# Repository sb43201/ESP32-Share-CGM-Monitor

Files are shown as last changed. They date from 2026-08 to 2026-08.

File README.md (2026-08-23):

# ESP32 Share CGM Desktop Monitor

An unofficial ESP32 desktop monitor that can display glucose data from a
Dexcom G7 CGM system through Dexcom Share.

Firmware **V3.1.0** targets the Hosyond/LCDWiki E32R35T desktop display:
ESP32-WROOM-32E, 480x320 ST7796 TFT, XPT2046 resistive touch, and onboard
microSD.

This is an independent community project. It is not affiliated with, authorized
by, sponsored by, or endorsed by Dexcom, Inc. The monitor retrieves readings
through an unofficial/private Dexcom Share interface over Wi-Fi and does not
communicate directly with a sensor over Bluetooth. That interface may change or
stop working without notice.

This project is an independent, noncommercial, open-source experimental passive
secondary CGM display. It has not been reviewed, cleared, or approved by FDA and
must not be relied upon for treatment decisions, medical alarms, diagnosis, or
replacement of an approved CGM application or receiver. Confirm unexpected
readings and alerts using the approved CGM workflow.

## V3.1.0 features

- live glucose value with Dexcom-provided trend arrow and description;
- color-coded glucose: red below 70, green from 70–180, and yellow above 180 mg/dL;
- touch-selectable 3H, 6H, 12H, and 24H TFT graphs with the last range
  restored after reboot;
- 70, 180, and 250 mg/dL graph references with a flashing visual threshold
  warning below 65 or above 250 mg/dL;
- persistent daily CSV logging to the onboard microSD slot;
- recovery of recent graph history after reboot;
- responsive web dashboard with live glucose, statistics, and 3H–30D history;
- streamed, downsampled 7D and 30D requests with bounded ESP32 memory use;
- CSV export for today, seven days, or a validated date range;
- captive-portal Wi-Fi and Dexcom publisher-account provisioning;
- configurable POSIX timezone, 12/24-hour clock, and screen-off schedule;
- center double-tap screen-off and touch-to-wake with temporary schedule override;
- TFT and web controls for clock format and four-point touch recalibration;
- graceful Wi-Fi, Dexcom, and SD failure recovery.

## Hardware mapping

| Function | ESP32 pin / bus |
|---|---:|
| TFT CS | GPIO 15, HSPI |
| TFT DC | GPIO 2 |
| TFT SCLK | GPIO 14 |
| TFT MOSI | GPIO 13 |
| TFT MISO | GPIO 12 |
| TFT backlight | GPIO 27 |
| Touch CS | GPIO 33, HSPI |
| Touch IRQ | GPIO 36 |
| SD CS | GPIO 5, VSPI |
| SD SCK | GPIO 18 |
| SD MISO | GPIO 19 |
| SD MOSI | GPIO 23 |

## Project media and enclosure

- [Project images](docs/images/) contains photographs, screenshots, and
  documentation graphics.
- [3D-printed enclosure](hardware/enclosure/) contains CAD, printable files,
  fabrication guidance, and assembly notes.

## Build and upload

Requirements: VS Code with PlatformIO, or PlatformIO Core.

```powershell
cd "PATH\TO\ESP32-Share-CGM-Monitor"
& "$env:USERPROFILE\.platformio\penv\Scripts\platformio.exe" run
& "$env:USERPROFILE\.platformio\penv\Scripts\platformio.exe" run -t upload --upload-port COM12
& "$env:USERPROFILE\.platformio\penv\Scripts\platformio.exe" device monitor --port COM12 --baud 115200
```

Change `COM12` if PlatformIO reports a different port. Close every serial monitor
before erase or upload operations.

To reproduce the complete first-boot workflow:

```powershell
& "$env:USERPROFILE\.platformio\penv\Scripts\platformio.exe" run -t erase --upload-port COM12
& "$env:USERPROFILE\.platformio\penv\Scripts\platformio.exe" run -t upload --upload-port COM12
```

## First boot

1. Complete the four-point touch calibration.
2. Read the welcome and safety screens; each remains visible for two seconds.
3. Join the displayed `CGMMonitor-Setup-XXXXXX` access point.
4. Open `http://192.168.4.1` if the captive page does not appear.
5. Select a 2.4 GHz Wi-Fi network.
6. Enter the Dexcom **publisher/sharer** login and password, not follower credentials.
7. Configure the hostname, timezone, clock, and optional screen schedule.
8. Save and wait for NTP, SD restoration, and Dexcom authentication.

Dexcom Share must be enabled with at least one follower configured. The saved
password is never returned by the dashboard or printed to Serial.

After the monitor joins the local network, open the dashboard at
`http://HOSTNAME.local` (normally `http://esp32-cgm-monitor.local`) or use the
IP address shown on the TFT System Status page. The `.local` address uses mDNS;
client devices or segmented networks without multicast DNS support must use the
numeric IP address.

## SD storage

The independent VSPI microSD interface writes one FAT32-compatible CSV file per
local day:

```text
/dexcom/YYYY/MM/YYYY-MM-DD.csv
```

Stable schema:

```csv
timestamp_iso,epoch_ms,glucose_mgdl,trend,trend_text
```

Epoch milliseconds are the canonical deduplication key. Each new record is
opened, appended, flushed, and closed. The logger warns below 100 MB free and
stops below 20 MB without interrupting glucose monitoring. Existing files are
never automatically deleted in V3.1.0.

## Web API

| Endpoint | Purpose |
|---|---|
| `/` | Responsive dashboard and settings |
| `/status` | Time, current glucose, SD, and non-secret device status |
| `/api/history?range=3h` | History; accepts 3h, 6h, 12h, 24h, 3d, 7d, or 30d |
| `/api/export/today` | Today's CSV download |
| `/api/export?days=7` | Last seven days |
| `/api/export?from=YYYY-MM-DD&to=YYYY-MM-DD` | Validated date-range export |

Short history comes from the bounded 288-reading RAM buffer. Longer history is
streamed from SD; 7D uses 15-minute bins and 30D uses hourly min/average/max bins.

## Protocol reference and acknowledgments

The Dexcom Share request flow and response conventions used by this project
were informed by [PyDexcom](https://github.com/gagebenne/pydexcom), an
independent Python client for Dexcom Share.

This firmware is an independent C++ implementation for ESP32. It does not
include, depend on, or require the PyDexcom Python package. Neither project is
affiliated with or endorsed by Dexcom, Inc.

## Security and limitations

- Dexcom Share is an unofficial/private API and may change without notice.
- HTTPS currently uses `WiFiClientSecure::setInsecure()`; service certificate
  validation is the highest-priority future security improvement.
- Wi-Fi and Dexcom setup pages use local HTTP.
- Dexcom credentials are stored in ESP32 NVS. NVS is not encrypted unless ESP32
  flash encryption is separately enabled.
- Retention selections are stored, but V3.1.0 does not automatically delete files.
- The official Share-style retrieval window is at most 24 hours / 288 readings;
  all longer history is accumulated locally on SD.

See [MANUAL.md](MANUAL.md) for operating and troubleshooting instructions.

## License

This project is released under the [MIT License](LICENSE).

The MIT License applies only to this project's original code and documentation.
It does not grant any rights to Dexcom trademarks, branding, software, APIs, or
services. Dexcom and Dexcom G7 are trademarks of Dexcom, Inc.; their names are
used only to describe compatibility and the source of data.

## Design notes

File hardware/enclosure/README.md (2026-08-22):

# 3D-Printed Enclosure

Store enclosure design and fabrication files here, such as:

- source CAD files;
- STL or 3MF exports;
- slicer profiles where useful;
- dimensioned drawings;
- assembly notes and hardware lists;
- enclosure photographs or renders specific to fabrication.

Document the supported display board revision, print orientation, material,
supports, fasteners, and any post-processing required for each released design.

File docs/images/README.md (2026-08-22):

# Project Images

Store public project media here, including:

- completed monitor photographs;
- TFT and web-dashboard screenshots;
- assembly and wiring photographs;
- documentation diagrams.

Before committing an image, check that it does not expose Wi-Fi credentials,
CGM account information, session identifiers, private network details, or
personal glucose history that should remain private.

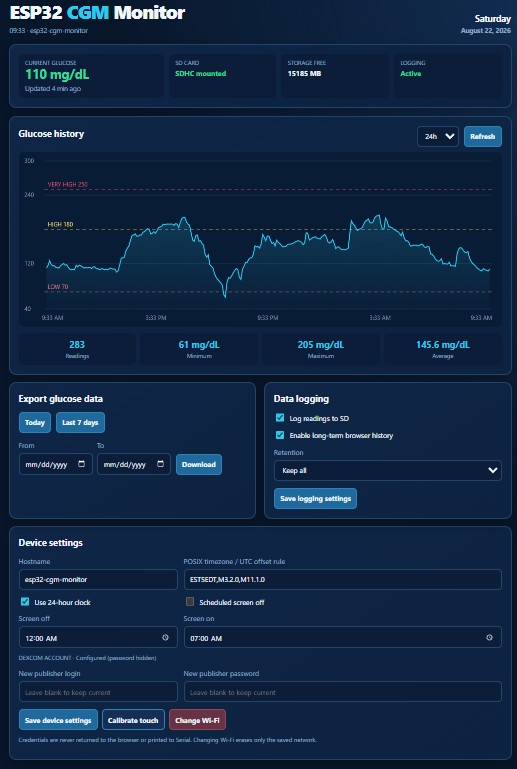
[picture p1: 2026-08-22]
docs/images/Screenshot 2026-08-22 093341.jpg

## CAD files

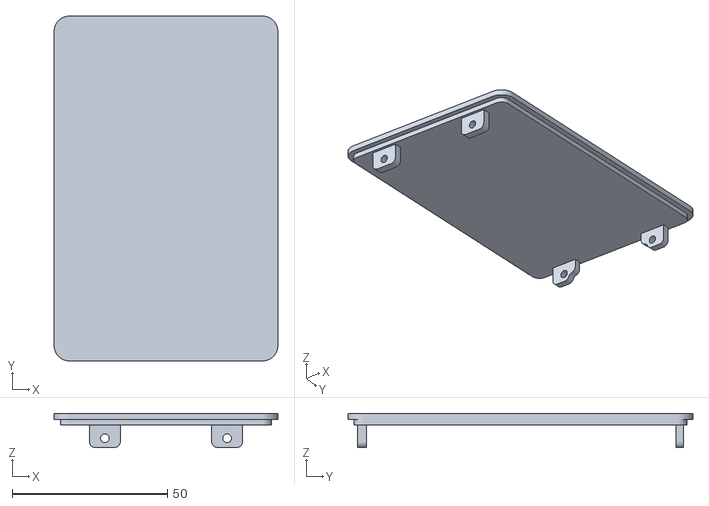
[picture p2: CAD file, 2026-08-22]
hardware/enclosure/ESP32 CGM Monitor - Case back.stl
72.0 x 111.0 x 11.0

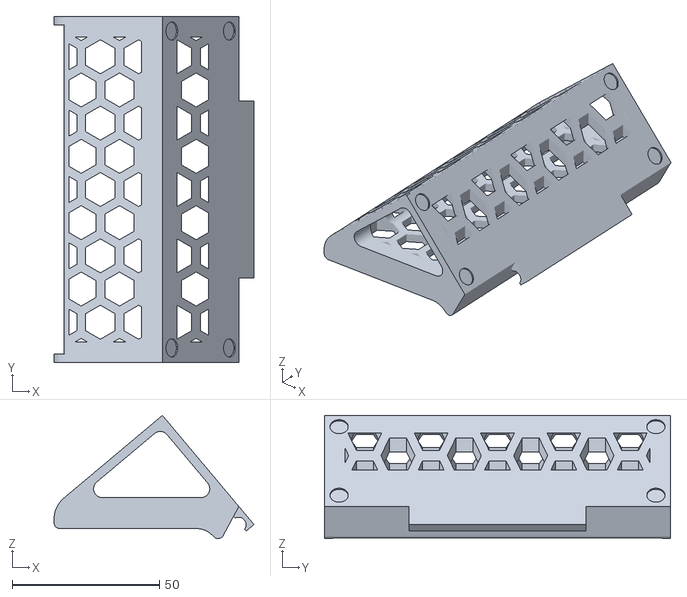
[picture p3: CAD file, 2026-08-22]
hardware/enclosure/ESP32 CGM Monitor - Stand desk.stl
67.9 x 117.5 x 41.8

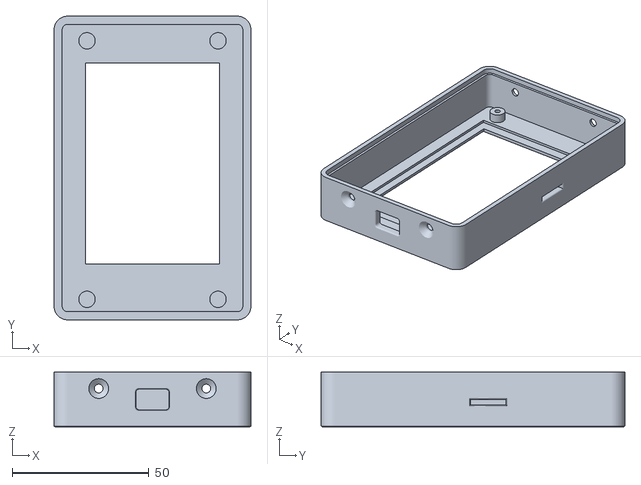
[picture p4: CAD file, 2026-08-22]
hardware/enclosure/ESP32 CGM Monitor - Case front.stl
72.0 x 111.0 x 20.0

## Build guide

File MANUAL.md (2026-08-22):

# ESP32 Share CGM Desktop Monitor V3.1.0 — User Manual

## 1. Safety

This independent, noncommercial, open-source experimental project is unofficial
and is not affiliated with or endorsed by Dexcom, Inc. It uses an
unofficial/private Dexcom Share interface that may change without notice. This
project is a passive secondary CGM display. It has not been reviewed, cleared,
or approved by FDA and must not be relied upon for treatment decisions, medical
alarms, diagnosis, or replacement of an approved CGM application or receiver.
Confirm unexpected readings and alerts through the approved CGM workflow.

## 2. Normal TFT display

The header shows local weekday/date, time, Wi-Fi state, CGM state, and the
**STATUS** touch target. The main area shows the latest glucose value, units,
Dexcom-provided arrow, and trend description.

Glucose value colors:

- red: below 70 mg/dL, or a reading older than 15 minutes;
- green: 70–180 mg/dL;
- yellow: above 180 mg/dL;
- visual threshold warning: flashing black on red below 65 or above 250 mg/dL.

The graph uses a fixed 40–300 mg/dL scale. Reference lines mark 70, 180, and
250 mg/dL. Touch **3H**, **6H**, **12H**, or **24H** to change the range. Tabs
respond on initial contact and use enlarged touch targets. The active tab is
dark teal with a cyan outline and yellow bottom bar. The selected range is saved
and restored after reboot; a device with no saved selection defaults to 3H.

The footer reports the reading age. A stale/offline message does not erase the
last known glucose value.

## 3. First-time setup

After a full flash erase:

1. Touch each of the four calibration targets and release.
2. Read the welcome screen and safety notice. Each displays for two seconds.
3. On a phone or computer, join `CGMMonitor-Setup-XXXXXX`.
4. If needed, browse to `http://192.168.4.1`.
5. Select the 2.4 GHz Wi-Fi network and enter its password.
6. Enter the Dexcom publisher/sharer login and password.
7. Enter the POSIX timezone rule. Indianapolis defaults to
   `EST5EDT,M3.2.0,M11.1.0`.
8. Select 12- or 24-hour time and optional screen-off/on times.
9. Save and allow the portal to close.

The monitor displays its LAN IP in Serial and on the Status screen.

The TFT System Status page also provides **Calibrate touch** and a persistent
**12H CLOCK**/**24H CLOCK** toggle.

## 4. Web dashboard

Open `http://DEVICE-IP/`. The dashboard shows current glucose and age, storage
state, graph, min/max/average, data export, logging controls, and device settings.

The 3H–24H views use recent RAM history. The 3D, 7D, and 30D views depend on data
accumulated by this monitor on SD; Dexcom Share cannot retrospectively fill those
ranges beyond approximately 24 hours.

Use **Calibrate touch** to start calibration on the TFT. Use **Change Wi-Fi** to
erase only saved network credentials and restart the captive portal. Saved
Dexcom credentials remain available. To replace Dexcom credentials, enter only
the fields being changed and save Device settings; passwords are never shown.

## 5. CSV export and SD card

Use **Today**, **Last 7 days**, or select From/To dates. Exports preserve the raw
five-minute CSV records. Date ranges are validated and cannot address arbitrary
SD paths.

The card can be read on a computer as FAT32. Files are under:

```text
/dexcom/year/month/date.csv
```

Do not remove the card while an append is being written. If removal or a write
failure occurs, monitoring continues in RAM and the firmware retries the card
every 60 seconds. On reinsertion, recent RAM readings are backfilled without
duplicating timestamps.

Below 100 MB free, the status shows a warning. Below 20 MB, SD logging stops.
Copy or delete old CSV files on a computer to regain space. V3.1.0 does not
perform automatic retention deletion.

## 6. Screen schedule

Enable Scheduled screen off and choose exact off/on times in the dashboard.
Overnight periods are supported. Only the TFT backlight turns off; Wi-Fi,
Dexcom polling, SD logging, and the web server continue running.

Double-tap the large center area of the dashboard to turn the TFT backlight off
manually. Tap anywhere once while the screen is dark to wake it. Manual off/on
temporarily overrides the configured schedule without changing its saved state
or times. Automatic control resumes at the next scheduled on/off transition or
when device settings are saved again; no reboot is required.

## 7. Status screen

Touch **STATUS** to view IP/RSSI, Dexcom/session state, reading age, NTP, uptime,
history size, heap, SD free space, and sanitized errors. Touch **BACK** to return.
No password, account ID, or full session token is displayed.

## 8. Troubleshooting

### Portal does not appear

Join the setup SSID manually and open `http://192.168.4.1`. The portal times out
after three minutes so the monitor can continue offline. Reboot to retry.

### Authentication fails

Use publisher/sharer credentials, confirm Share is enabled and at least one
follower exists, verify the password, and check that the account is in the US
region supported by the configured endpoint.

### HTTPS request stalls or fails

Check RSSI on the Status screen. Values near -80 dBm are weak; move the monitor
closer to the router. DNS, TLS, and server outages are retried without discarding
the last reading.

### SD is unavailable

Power down, reseat a FAT32 card, and reboot. Monitoring works without a card but
history is then limited to RAM and cannot survive a power loss.

### Touch is inaccurate

Use the dashboard's **Calibrate touch** button and complete all four targets.
Calibration is stored in NVS until the flash is erased.

### COM port is busy

Close PlatformIO/Arduino serial monitors before erase or upload. Check the port:

```powershell
& "$env:USERPROFILE\.platformio\penv\Scripts\platformio.exe" device list
```

## 9. Factory workflow test

Erasing flash removes firmware, Wi-Fi, Dexcom credentials, settings, and touch
calibration. It does not erase the SD card.

```powershell
& "$env:USERPROFILE\.platformio\penv\Scripts\platformio.exe" run -t erase --upload-port COM12
& "$env:USERPROFILE\.platformio\penv\Scripts\platformio.exe" run -t upload --upload-port COM12
```

Use a blank SD card or temporarily remove it if testing a completely new system.

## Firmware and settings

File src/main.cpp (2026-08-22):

#include <Arduino.h>
#include <ESPmDNS.h>
#include <Preferences.h>
#include <WiFi.h>
#include <esp_heap_caps.h>
#include <math.h>

#include "Config.h"
#include "DexcomClient.h"
#include "DeviceSettings.h"
#include "DisplayUI.h"
#include "GlucoseHistory.h"
#include "SDLogger.h"
#include "TimeManager.h"
#include "WebDashboard.h"
#include "WifiProvisioner.h"

DisplayUI display;
DexcomClient dexcom;
TimeManager timeManager;
GlucoseHistory glucoseHistory;
SDLogger sdLogger;
DeviceSettings deviceSettings;
WifiProvisioner wifiProvisioner(deviceSettings);
WebDashboard webDashboard(glucoseHistory, sdLogger, deviceSettings);
GlucoseReading latestReading;
// Reused API scratch buffer. History itself uses compact HistoryPoint entries.
GlucoseReading fetchedReadings[MAX_HISTORY_READINGS];
size_t fetchedCount = 0;
AppState appState = AppState::BOOT;
UiScreen uiScreen = UiScreen::DASHBOARD;
HistoryRange selectedRange = HistoryRange::H3;
String stateDetail;
uint64_t lastSuccessfulRequestMs = 0;
uint32_t lastWifiAttempt = 0, lastPoll = 0, lastDisplay = 0, lastHeapLog = 0;
uint32_t lastMdnsAttempt = 0;
bool ntpStarted = false, ntpWasSynced = false;
bool webStarted = false;
bool mdnsStarted = false;
bool graphDirty = true, screenDirty = true;

enum class ScreenOverride : uint8_t { AUTO, FORCE_ON, FORCE_OFF };
ScreenOverride screenOverride = ScreenOverride::AUTO;
bool scheduleStateInitialized = false;
bool lastScheduledOff = false;

void loadHistoryRangePreference() {
  Preferences preferences;
  preferences.begin("dexcomui", false);
  const uint8_t savedHours = preferences.isKey("historyRange")
      ? preferences.getUChar("historyRange", 3) : 3;
  preferences.end();
  if (savedHours == 6) selectedRange = HistoryRange::H6;
  else if (savedHours == 12) selectedRange = HistoryRange::H12;
  else if (savedHours == 24) selectedRange = HistoryRange::H24;
  else selectedRange = HistoryRange::H3;
  Serial.printf("[UI] Restored history range: %uH\n",
                static_cast<unsigned>(selectedRange));
}

void saveHistoryRangePreference() {
  Preferences preferences;
  preferences.begin("dexcomui", false);
  preferences.putUChar("historyRange", static_cast<uint8_t>(selectedRange));
  preferences.end();
}

void startWifi() {
  Serial.println("[WIFI] Connecting using saved credentials..."); WiFi.mode(WIFI_STA); WiFi.reconnect();
  lastWifiAttempt = millis(); appState = AppState::WIFI_CONNECTING;
}

void startMdns() {
  if (WiFi.status() != WL_CONNECTED) return;
  lastMdnsAttempt = millis();
  if (mdnsStarted) { MDNS.end(); mdnsStarted = false; }
  const String &hostname = deviceSettings.data().hostname;
  if (MDNS.begin(hostname.c_str())) {
    MDNS.addService("http", "tcp", 80);
    mdnsStarted = true;
    Serial.printf("[MDNS] Dashboard available at http://%s.local\n", hostname.c_str());
  } else {
    Serial.println("[MDNS] Failed to start; will retry");
  }
}

void updateWifi() {
  static bool wasConnected = false;
  const bool connected = WiFi.status() == WL_CONNECTED;
  if (connected && !wasConnected) {
    Serial.println("[WIFI] Connected"); Serial.printf("[WIFI] IP: %s\n", WiFi.localIP().toString().c_str());
    Serial.printf("[WIFI] RSSI: %d dBm\n", WiFi.RSSI());
    startMdns();
    if (!ntpStarted) { timeManager.begin(deviceSettings.data().timezone, deviceSettings.data().clock24Hour); ntpStarted = true; appState = AppState::TIME_SYNC; }
    lastPoll = 0; screenDirty = true;
    if (!webStarted) { webDashboard.begin(); webStarted = true; }
  } else if (!connected && wasConnected) {
    if (mdnsStarted) { MDNS.end(); mdnsStarted = false; }
    Serial.println("[WIFI] Disconnected; retaining glucose and history");
    appState = AppState::NETWORK_ERROR; stateDetail = "Wi-Fi disconnected"; screenDirty = true;
  }
  if (connected && !mdnsStarted && millis() - lastMdnsAttempt >= 5000)
    startMdns();
  if (!connected && millis() - lastWifiAttempt >= WIFI_RETRY_INTERVAL_MS) {
    Serial.println("[WIFI] Retrying connection"); WiFi.reconnect(); lastWifiAttempt = millis();
  }
  wasConnected = connected;
}

#if USE_MOCK_DEXCOM_DATA
void initializeMock() {
  glucoseHistory.generateMock24Hours(timeManager.nowMs());
  const HistoryPoint &last = glucoseHistory.points()[glucoseHistory.count() - 1];
  latestReading.value = last.value; latestReading.timestampMs = last.timestampMs;
  latestReading.trend = "Flat"; latestReading.valid = true; appState = AppState::NORMAL;
  graphDirty = true;
}

void advanceMock() {
  static const char *trends[] = {"Flat", "FortyFiveUp", "SingleUp", "Flat",
      "FortyFiveDown", "SingleDown", "Flat", "DoubleUp"};
  static size_t step = 0;
  if (!glucoseHistory.count()) { initializeMock(); return; }
  GlucoseReading simulated;
  simulated.value = 120 + static_cast<int>(18.0f * sinf(step * 0.55f));
  simulated.trend = trends[step % (sizeof(trends) / sizeof(trends[0]))];
  simulated.timestampMs = timeManager.nowMs(); simulated.valid = true;
  glucoseHistory.merge(&simulated, 1); latestReading = simulated;
  ++step; graphDirty = true; appState = AppState::NORMAL;
}
#endif

DexcomResult fetchAndMerge(uint16_t minutes, size_t maxCount) {
  fetchedCount = 0;
  const DexcomResult result = dexcom.getRecentReadings(fetchedReadings, maxCount, fetchedCount, minutes);
  if (result == DexcomResult::OK && fetchedCount) {
    latestReading = fetchedReadings[0];
    if (glucoseHistory.merge(fetchedReadings, fetchedCount)) graphDirty = true;
    sdLogger.logReadings(fetchedReadings, fetchedCount);
    lastSuccessfulRequestMs = timeManager.nowMs(); appState = AppState::NORMAL; stateDetail = "";
  }
  return result;
}

void restoreHistoryFromSD() {
  if (!timeManager.isSynchronized() || !sdLogger.status().mounted) return;
  fetchedCount = sdLogger.restoreRecent(fetchedReadings, MAX_HISTORY_READINGS,
                                        timeManager.nowMs());
  if (fetchedCount) {
    glucoseHistory.merge(fetchedReadings, fetchedCount);
    latestReading = fetchedReadings[fetchedCount - 1];
    graphDirty = true;
  }
}

void handleDexcomFailure(DexcomResult result) {
  stateDetail = dexcom.lastError();
  if (result == DexcomResult::AUTH_FAILED) appState = AppState::AUTH_ERROR;
  else if (result == DexcomResult::EMPTY_DATA) appState = AppState::NO_DATA;
  else appState = AppState::NETWORK_ERROR;
  Serial.printf("[DEXCOM] Error: %s\n", stateDetail.c_str()); screenDirty = true;
}

void pollDexcom() {
  if (WiFi.status() != WL_CONNECTED || !timeManager.isSynchronized()) return;
  appState = dexcom.hasSession() ? AppState::LOADING : AppState::DEXCOM_AUTH;
#if USE_MOCK_DEXCOM_DATA
  advanceMock();
#else
  const bool startup = glucoseHistory.count() == 0;
  const uint16_t minutes = startup ? 180 : 30;
  const size_t count = startup ? 36 : DEXCOM_READING_COUNT;
  const DexcomResult result = fetchAndMerge(minutes, count);
  if (result != DexcomResult::OK) handleDexcomFailure(result);
#endif
  lastPoll = millis(); screenDirty = true;
}

void loadSelectedRangeIfNeeded() {
#if USE_MOCK_DEXCOM_DATA
  graphDirty = true;
#else
  if (glucoseHistory.covers(selectedRange, timeManager.nowMs()) || WiFi.status() != WL_CONNECTED) {
    graphDirty = true; return;
  }
  Serial.printf("[CGM] Loading %u-hour history on demand\n", static_cast<unsigned>(selectedRange));
  const DexcomResult result = fetchAndMerge(GlucoseHistory::minutesFor(selectedRange),
                                             GlucoseHistory::expectedCount(selectedRange));
  if (result != DexcomResult::OK) handleDexcomFailure(result);
#endif
  graphDirty = true;
}

void handleTouch() {
  const TouchAction action = display.updateTouch(uiScreen);
  if (action == TouchAction::NONE) return;
  if (action == TouchAction::SCREEN_OFF) {
    screenOverride = ScreenOverride::FORCE_OFF;
    display.setBacklight(false);
    Serial.println("[DISPLAY] Manual screen-off override");
    return;
  } else if (action == TouchAction::WAKE_SCREEN) {
    screenOverride = ScreenOverride::FORCE_ON;
    display.setBacklight(true);
    Serial.println("[DISPLAY] Manual wake override");
    return;
  } else if (action == TouchAction::SHOW_STATUS) uiScreen = UiScreen::STATUS;
  else if (action == TouchAction::SHOW_DASHBOARD) uiScreen = UiScreen::DASHBOARD;
  else if (action == TouchAction::CALIBRATE_TOUCH) {
    display.setBacklight(true);
    display.calibrateTouch();
    Serial.println("[TOUCH] Calibration requested from system page");
  } else if (action == TouchAction::TOGGLE_CLOCK_FORMAT) {
    auto &settings = deviceSettings.data();
    settings.clock24Hour = !settings.clock24Hour;
    deviceSettings.save();
    timeManager.setClock24Hour(settings.clock24Hour);
    Serial.printf("[TIME] Clock format changed to %s from system page\n",
                  settings.clock24Hour ? "24-hour" : "12-hour");
  } else {
    const HistoryRange previousRange = selectedRange;
    if (action == TouchAction::RANGE_3H) selectedRange = HistoryRange::H3;
    else if (action == TouchAction::RANGE_6H) selectedRange = HistoryRange::H6;
    else if (action == TouchAction::RANGE_12H) selectedRange = HistoryRange::H12;
    else if (action == TouchAction::RANGE_24H) selectedRange = HistoryRange::H24;
    if (selectedRange != previousRange) saveHistoryRangePreference();
    Serial.printf("[TOUCH] History range: %uH\n", static_cast<unsigned>(selectedRange));
    loadSelectedRangeIfNeeded();
  }
  display.invalidate(); screenDirty = true;
}

StatusData makeStatusData(int64_t age) {
  StatusData status;
  status.wifiConnected = WiFi.status() == WL_CONNECTED; status.rssi = status.wifiConnected ? WiFi.RSSI() : 0;
  status.ip = status.wifiConnected ? WiFi.localIP().toString() : "--";
  status.dexcomConnected = appState == AppState::NORMAL || appState == AppState::STALE_DATA;
  status.sessionActive = dexcom.hasSession(); status.ntpSynchronized = timeManager.isSynchronized();
  status.clock24Hour = deviceSettings.data().clock24Hour;
  status.hostname = deviceSettings.data().hostname;
  status.lastSuccessMs = lastSuccessfulRequestMs; status.latestReadingMs = latestReading.timestampMs;
  status.readingAgeMinutes = age; status.historyCount = glucoseHistory.count();
  status.oldestReadingMs = glucoseHistory.oldestTimestampMs(); status.uptimeSeconds = millis() / 1000;
  status.freeHeap = ESP.getFreeHeap(); status.minHeap = ESP.getMinFreeHeap(); status.lastError = stateDetail;
  const SDLoggerStatus &sd = sdLogger.status();
  status.sdMounted = sd.mounted; status.sdLowSpace = sd.lowSpace || sd.loggingStopped;
  status.sdType = sd.cardType; status.sdFreeBytes = sd.freeBytes;
  status.sdCurrentFile = sd.currentFile; status.sdLastWriteMs = sd.lastWriteTimestampMs;
  return status;
}

void setup() {
  Serial.begin(115200); delay(100); Serial.printf("\n[BOOT] ESP32 Share CGM Monitor v%s\n", FIRMWARE_VERSION);
  loadHistoryRangePreference();
  display.begin();
  display.showWelcome(FIRMWARE_VERSION); delay(2000);
  display.showSafetyWarning(); delay(2000);
  sdLogger.begin(); deviceSettings.load();
  Serial.printf("[WIFI] Initial setup: join %s and open http://192.168.4.1\n", wifiProvisioner.setupSsid().c_str());
  display.showWifiSetup(wifiProvisioner.setupSsid());
  wifiProvisioner.begin(); lastWifiAttempt = millis();
  dexcom.setCredentials(deviceSettings.data().dexcomLogin, deviceSettings.data().dexcomPassword);
  display.invalidate(); screenDirty = true;
}

void updateScreenSchedule() {
  const auto &s = deviceSettings.data(); bool scheduledOff = false;
  if (s.screenScheduleEnabled && timeManager.isSynchronized() && s.screenOffMinute != s.screenOnMinute) {
    time_t stamp=time(nullptr); struct tm local{}; localtime_r(&stamp,&local);
    const uint16_t minute=local.tm_hour*60+local.tm_min;
    scheduledOff=s.screenOffMinute<s.screenOnMinute ? minute>=s.screenOffMinute&&minute<s.screenOnMinute
                                                     : minute>=s.screenOffMinute||minute<s.screenOnMinute;
  }
  if (!scheduleStateInitialized) {
    lastScheduledOff = scheduledOff;
    scheduleStateInitialized = true;
  } else if (scheduledOff != lastScheduledOff) {
    lastScheduledOff = scheduledOff;
    screenOverride = ScreenOverride::AUTO;
    Serial.println("[DISPLAY] Scheduled transition restored automatic control");
  }
  bool off = scheduledOff;
  if (screenOverride == ScreenOverride::FORCE_ON) off = false;
  else if (screenOverride == ScreenOverride::FORCE_OFF) off = true;
  display.setBacklight(!off);
}

void loop() {
  updateWifi(); handleTouch();
  webDashboard.setNow(timeManager.nowMs()); if (webStarted) webDashboard.handle();
  if (webDashboard.consumeTouchCalibrationRequest()) { display.setBacklight(true); display.calibrateTouch(); display.invalidate(); screenDirty=true; }
  if (webDashboard.consumeDeviceSettingsChanged()) {
    dexcom.setCredentials(deviceSettings.data().dexcomLogin, deviceSettings.data().dexcomPassword);
    lastPoll=0;
    timeManager.begin(deviceSettings.data().timezone, deviceSettings.data().clock24Hour);
    startMdns();
    screenOverride=ScreenOverride::AUTO; scheduleStateInitialized=false;
    ntpStarted=true; ntpWasSynced=false; display.invalidate(); screenDirty=true;
  }
  if (webDashboard.consumeWifiResetRequest()) {
    Serial.println("[WIFI] Erasing saved network and restarting provisioning"); delay(250); WiFi.disconnect(true, true); delay(250); ESP.restart();
  }
  updateScreenSchedule();
  if (timeManager.isSynchronized() && !ntpWasSynced) {
    ntpWasSynced = true; Serial.println("[NTP] Time synchronized"); appState = AppState::LOADING; screenDirty = true;
    restoreHistoryFromSD();
  }
  const bool wasSdMounted = sdLogger.status().mounted;
  const bool isSdMounted = sdLogger.update();
  if (!wasSdMounted && isSdMounted && timeManager.isSynchronized()) {
    restoreHistoryFromSD();
    sdLogger.backfill(glucoseHistory.points(), glucoseHistory.count()); screenDirty = true;
  }
  if (WiFi.status() == WL_CONNECTED && timeManager.isSynchronized() &&
      (lastPoll == 0 || millis() - lastPoll >= DEXCOM_POLL_INTERVAL_MS)) pollDexcom();

  const int64_t age = timeManager.readingAgeMinutes(latestReading.timestampMs);
  if (latestReading.valid && appState != AppState::NETWORK_ERROR && appState != AppState::AUTH_ERROR) {
    if (age > 15) appState = AppState::NO_DATA; else if (age >= 8) appState = AppState::STALE_DATA;
    else appState = AppState::NORMAL;
  }
  if (screenDirty || millis() - lastDisplay >= DISPLAY_REFRESH_INTERVAL_MS) {
    if (uiScreen == UiScreen::DASHBOARD) {
      display.renderDashboard(appState, latestReading, age, timeManager.clockText(),
          WiFi.status() == WL_CONNECTED, selectedRange, glucoseHistory,
          timeManager.nowMs(), graphDirty);
      graphDirty = false;
    } else display.renderStatus(makeStatusData(age), timeManager.clockText(), screenDirty);
    lastDisplay = millis(); screenDirty = false;
  }
  if (millis() - lastHeapLog >= HEAP_LOG_INTERVAL_MS) {
    Serial.printf("[SYS] Free heap: %u, min: %u, largest: %u, uptime: %us\n",
        ESP.getFreeHeap(), ESP.getMinFreeHeap(), heap_caps_get_largest_free_block(MALLOC_CAP_8BIT), millis() / 1000);
    Serial.printf("[CGM] History count: %u / %u\n", glucoseHistory.count(), MAX_HISTORY_READINGS);
    lastHeapLog = millis();
  }
  delay(5);
}

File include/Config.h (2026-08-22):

#pragma once
#include <Arduino.h>

#define USE_MOCK_DEXCOM_DATA 0
#define FORCE_TOUCH_CALIBRATION 0
#define FIRMWARE_VERSION "3.1.0"

constexpr uint32_t DEXCOM_POLL_INTERVAL_MS = 60000;
constexpr uint32_t WIFI_RETRY_INTERVAL_MS = 10000;
constexpr uint32_t DISPLAY_REFRESH_INTERVAL_MS = 1000;
constexpr uint32_t HEAP_LOG_INTERVAL_MS = 300000;
constexpr uint32_t HTTP_TIMEOUT_MS = 15000;
constexpr uint8_t DEXCOM_READING_COUNT = 6;
constexpr uint16_t DEXCOM_READING_MINUTES = 1440;
constexpr size_t MAX_HISTORY_READINGS = 288;
constexpr int CRITICAL_LOW_REFERENCE = 65;
constexpr int LOW_REFERENCE = 70;
constexpr int HIGH_REFERENCE = 180;
constexpr int VERY_HIGH_REFERENCE = 250;
constexpr int TOUCH_MIN_X = 300;
constexpr int TOUCH_MAX_X = 3800;
constexpr int TOUCH_MIN_Y = 280;
constexpr int TOUCH_MAX_Y = 3850;
constexpr uint8_t SD_CS_PIN = 5;
constexpr uint8_t SD_SCK_PIN = 18;
constexpr uint8_t SD_MISO_PIN = 19;
constexpr uint8_t SD_MOSI_PIN = 23;
constexpr uint32_t SD_RETRY_INTERVAL_MS = 60000;
constexpr uint64_t SD_WARN_FREE_BYTES = 100ULL * 1024ULL * 1024ULL;
constexpr uint64_t SD_STOP_FREE_BYTES = 20ULL * 1024ULL * 1024ULL;

constexpr char TIMEZONE[] = "EST5EDT,M3.2.0,M11.1.0";
constexpr char NTP_SERVER_1[] = "pool.ntp.org";
constexpr char NTP_SERVER_2[] = "time.nist.gov";

enum class AppState {
  BOOT, WIFI_CONNECTING, TIME_SYNC, DEXCOM_AUTH, LOADING, NORMAL,
  STALE_DATA, NETWORK_ERROR, AUTH_ERROR, NO_DATA
};

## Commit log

2026-08-22 Add project image and printable enclosure files
    [ESP32 CGM Monitor - Case back.stl, ESP32 CGM Monitor - Case front.stl, ESP32 CGM Monitor - Stand desk.stl]
2026-08-22 Restore schedule control without reboot
    [main.cpp]
